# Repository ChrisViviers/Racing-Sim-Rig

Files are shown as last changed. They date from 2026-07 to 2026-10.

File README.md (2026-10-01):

# DIY Sim Racing Wheel & Gear-Driven Pedals (Raspberry Pi Pico 2 + Adafruit AS5600)

A high-precision, zero-friction USB Sim Racing Steering Wheel and Pedal set built using a **Raspberry Pi Pico 2WH** (RP2350 microcontroller), an **Adafruit AS5600** magnetic rotary encoder over I2C, gear-driven potentiometer pedals, custom tactile buttons, and a laser-cut/3D-printed rig frame.

This project reads 12-bit contactless magnetic steering data (0–4095) and 16-bit analog potentiometer pedal data, mapping them down to clean, unsigned 8-bit HID Gamepad axes (0–255) in CircuitPython.

## Table of Contents

- [Features](#features)
- [Hardware Bill of Materials](#hardware-bill-of-materials-bom)
- [3D Printed & Laser Cut Parts](#3d-printed--laser-cut-parts)
- [Pinout and Wiring](#pinout-and-wiring)
- [Software Setup](#software-setup)
- [Pedal Calibration](#pedal-calibration)

---

## Features

- **Contactless Precision Steering:** Uses the Adafruit AS5600 magnetic sensor to track a diametrically magnetized magnet with zero physical wear.
- **Gear-Driven Pedal:** Stepped-up gear ratio assembly (80T pedal gear to 20T pot gear, connected by a timing belt) provides smooth, high-resolution pedal modulation.
- **RP2350 Microcontroller:** Powered by the Raspberry Pi Pico 2WH running CircuitPython.
- **8 Integrated Inputs:** Support for 8 tactile push buttons or paddle shifters using internal pull-up resistors.
- **Auto-Inverting Pedal Calibration:** Robust calibration math handles custom potentiometer mechanical sweep directions (whether voltage sweeps up or down) automatically.
- **Modular RJ45 Cabling:** Floor pedal signals route up to the steering base through a standard Cat5e Ethernet patch cable and RJ45 breakout modules.
- **Plug-and-Play USB HID:** Enumerates directly as a standard USB Gamepad recognized by games like RaceRoom, Assetto Corsa, and iRacing without third-party software.

---

## Hardware Bill of Materials (BOM)

| Component | Quantity | Description / Notes |
| --- | --- | --- |
| **Raspberry Pi Pico 2WH** | 1 | RP2350 microcontroller running CircuitPython |
| **Adafruit AS5600 Breakout** | 3 | 12-bit I2C Magnetic Rotary Encoder |
| **Diametric Magnet** | 3 | Neodymium disc magnet (**must be diametrically magnetized**) |
| **10k Linear Potentiometers (B10K)** | 2 | Throttle and brake pedal sensors |
| **Switches** | 2 | Inputs for wheel buttons and paddle shifters |
| **Timing Belt & Pulleys** | Set | Drives the 20T potentiometer gear from the 80T pedal gear |
| **RJ45 Breakout Modules** | 4 | Modular connection for floor pedals to wheel base |
| **Cat5e / Cat6 Patch Cable** | 2 | Umbilical cable connecting pedals to steering wheel housing |
| **8mm Steel Rod & Bearings** | Set | Shaft stock used across the pedal, steering, and shifter parts  |
| **Laser Cut / 3D Printed Parts** | Set | See [3D Printed & Laser Cut Parts](#3d-printed--laser-cut-parts) |
| **Prototyping Board** | 1 | Circuit interconnects |
| **M5x35 Nuts & Bolts** | 20 | Connecting Laser Cuts |
| **M5x16 Nuts & Bolts** | 15 | Connecting Laser Cuts |
| **M5 Threaded Inserts** | 4 | Connecting Laser Cuts |
| **M3x16 Nuts & Bolts** | 20 | Connecting Laser Cuts |
| **M2.5x20 Nuts & Bolts** | 4 | Connecting Laser Cuts |
| **M2.5x16 Nuts & Bolts** | 12 | Connecting Laser Cuts |
| **6mm MDF Sheert 1000mmx600mm** | 1 | Material for Laser Cuts |
| **85mm Compression Spring** | 2 | For Lifting Pedals |
| **Qwiic JST-SH 4-pin to Male Jumper Wires** | 3 | For Connecting AS5600 sensors |
| **8mm Shaft Collar** | 4 | For Keeping Rods in Place |
| **200mm Male to Male Jumper Cables** | 4 | Circuit interconnects |
| **100mm Male to Male Jumper Cables** | 12 | Circuit interconnects |
| **8mm Pillow Block Bearing** | 6 | Connecting Laser Cuts |
| **8mm 8mm Flange Pillow Block Bearing** | 4 | Connecting Laser Cuts |
| **8mm Steel Rod & Bearings 90mm** | 1 | Shaft stock used across the pedal, steering, and shifter parts  |
| **8mm Steel Rod & Bearings 200mm** | 1 | Shaft stock used across the pedal, steering, and shifter parts  |
| **8mm Steel Rod & Bearings 160mm** | 2 | Shaft stock used across the pedal, steering, and shifter parts  |
| **8mm Steel Rod & Bearings 70mm** | 2 | Shaft stock used across the pedal, steering, and shifter parts  |
| **8mm Steel Rod & Bearings 125mm** | 2 | Shaft stock used across the pedal, steering, and shifter parts  |

---

## 3D Printed & Laser Cut Parts

All CAD source files are in the repository root:

| File | Description |
| ---- | --- |
| [`racingSimPotFullLaser6mm.svg`](https://github.com/ChrisViviers/Racing-Sim-Rig/blob/main/racingSimPotFullLaser6mm.svg) | Laser cut template for the entire rig frame (6mm material). |
| [`RacingSim HE Blueprint.svg`](https://github.com/ChrisViviers/Racing-Sim-Rig/blob/main/RacingSim%20HE%20Blueprint.svg) | Laser cut template for the entire rig frame AS5600 Alternative (6mm material). |
| [`Racing Wheel.stl`](https://github.com/ChrisViviers/Racing-Sim-Rig/blob/main/Racing%20Wheel.stl) | 3D printable racing wheel. |
| [`8mmRodTAdapterPedal.stl`](https://github.com/ChrisViviers/Racing-Sim-Rig/blob/main/8mmRodTAdapterPedal.stl) | T-adapter for the pedal that attaches a rod perpendicular to another rod in the pedal assembly. |
| [`80TGearPedalAdapter.stl`](https://github.com/ChrisViviers/Racing-Sim-Rig/blob/main/80TGearPedalAdapter.stl) | 80-tooth gear that attaches to the pedal. |
| [`20TGear10kPotAdapter.stl`](https://github.com/ChrisViviers/Racing-Sim-Rig/blob/main/20TGear10kPotAdapter.stl) | 20-tooth gear that attaches to the potentiometers; connected to the 80T pedal gear via a timing belt. |
| [`8mmRodMagnetAdapter.stl`](https://github.com/ChrisViviers/Racing-Sim-Rig/blob/main/8mmRodMagnetAdapter.stl) | Attaches the steering wheel's AS5600 magnet to an 8mm shaft. |
| [`ShifterLaserToShaftAdapter.stl`](https://github.com/ChrisViviers/Racing-Sim-Rig/blob/main/ShifterLaserToShaftAdapter.stl) | Adapts the laser-cut design to an 8mm shaft for the sequential shifter. |

---

## Pinout and Wiring

### 1. Steering & Pedal Connections

| Sensor / Component | Module Pin | Pico 2 Pin | Function |
| --- | --- | --- | --- |
| **AS5600 Steering** | VIN | 3.3V (Pin 36) | Power Rail |
| **AS5600 Steering** | GND | GND (Pin 38)  | Ground Rail |
| **AS5600 Steering** | SDA | GP0 (Pin 1) | I2C Data |
| **AS5600 Steering** | SCL | GP1 (Pin 2) | I2C Clock |
| **Throttle Potentiometer**  | Pin 1 (Outer)  | 3.3V (Pin 36) | Power Rail |
| **Throttle Potentiometer**  | Pin 2 (Center) | GP26 (Pin 31) | ADC0 Analog Input |
| **Throttle Potentiometer**  | Pin 3 (Outer)  | GND (Pin 38)  | Ground Rail |
| **Brake Potentiometer** | Pin 1 (Outer)  | 3.3V (Pin 36) | Power Rail |
| **Brake Potentiometer** | Pin 2 (Center) | GP27 (Pin 32) | ADC1 Analog Input |
| **Brake Potentiometer** | Pin 3 (Outer)  | GND (Pin 38)  | Ground Rail |

### 2. Modular Pedal Extension (RJ45 / Cat5e)

| RJ45 Pin  | Pico 2 / Wheel Base | Floor Pedal Box | Function |
| --- | --- | --- | --- |
| **Pin 1** | 3.3V (Pin 36) | Potentiometer Pin 1 | Power Rail |
| **Pin 2** | GND (Pin 38) | Potentiometer Pin 3 | Ground Rail |
| **Pin 3** | GP26 (ADC0) | Potentiometer Pin 2 | Throttle Signal Line |
| **Pin 4** | GP27 (ADC1) | Potentiometer Pin 2 | Brake Signal Line |

### 3. Button Wiring (Active-LOW)

All buttons connect between their designated GPIO pin and GND (using the Pico's internal pull-up resistors):

- **Button 1:** GP6 -> Switch -> GND
- **Button 2:** GP7 -> Switch -> GND
- **Button 3:** GP8 -> Switch -> GND
- **Button 4:** GP9 -> Switch -> GND
- **Button 5 (Left Shifter):** GP10 -> Switch -> GND
- **Button 6 (Right Shifter):** GP11 -> Switch -> GND
- **Button 7:** GP12 -> Switch -> GND
- **Button 8:** GP13 -> Switch -> GND

---

## Software Setup

### Prerequisites

1. Download the latest CircuitPython `.uf2` firmware for the **Raspberry Pi Pico 2**.
2. Download the official **Adafruit CircuitPython Library Bundle**.

### Installation

1. **Flash CircuitPython:** Hold down the `BOOTSEL` button on your Pico 2, connect it to your PC via USB, and drop the downloaded `.uf2` file onto the `RPI-RP2` drive.
2. **Install Libraries:** Copy `adafruit_as5600.mpy` from the Adafruit bundle into the `lib/` directory on your `CIRCUITPY` drive.
3. **Add Project Files:** Copy `boot.py`, `code.py`, and `hid_gamepad.py` from this repository directly to the root of your `CIRCUITPY` drive.
4. **Reboot:** Eject the drive safely and reconnect the Pico 2 to initialize the new USB device profile.

---

## Pedal Calibration

Because custom gear-driven potentiometers vary by build, calibrate your pedal limits in `code.py`:

1. Run a basic analog read script to measure the raw ADC value at **Rest** and **Floored** for each pedal.
2. Update the constants in `code.py`:

\`\`\`python
#### Measured calibration limits
THROTTLE_REST    = 800
THROTTLE_FLOORED = 23300
BRAKE_REST       = 3400
BRAKE_FLOORED    = 24000
\`\`\`

The mapping function handles both increasing and inverted potentiometer sweep directions automatically, so it doesn't matter which end of the pedal's travel reads the higher raw value.

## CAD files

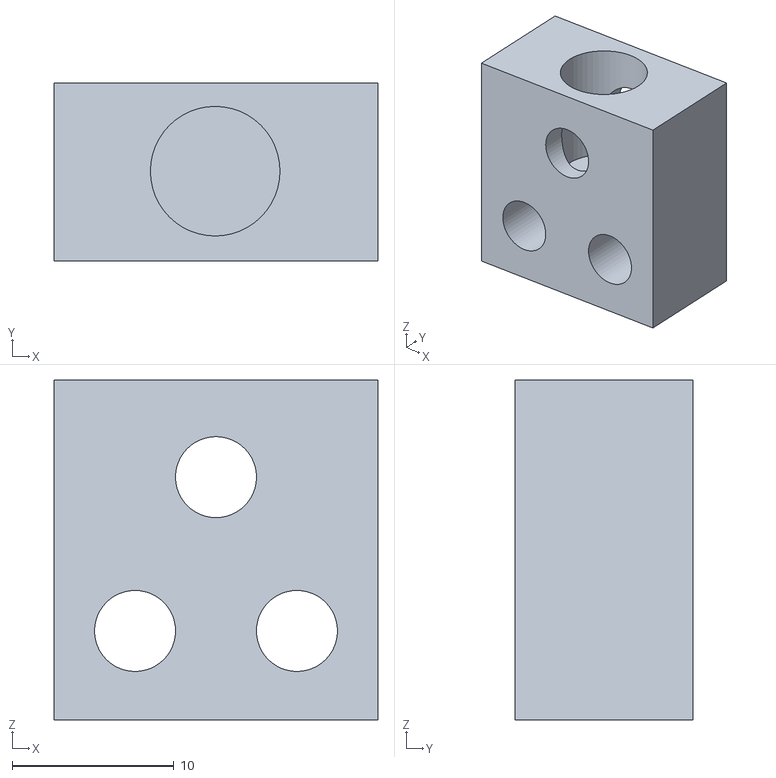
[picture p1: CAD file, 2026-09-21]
ShifterLaserToShaftAdapter.stl
20.0 x 11.0 x 21.0

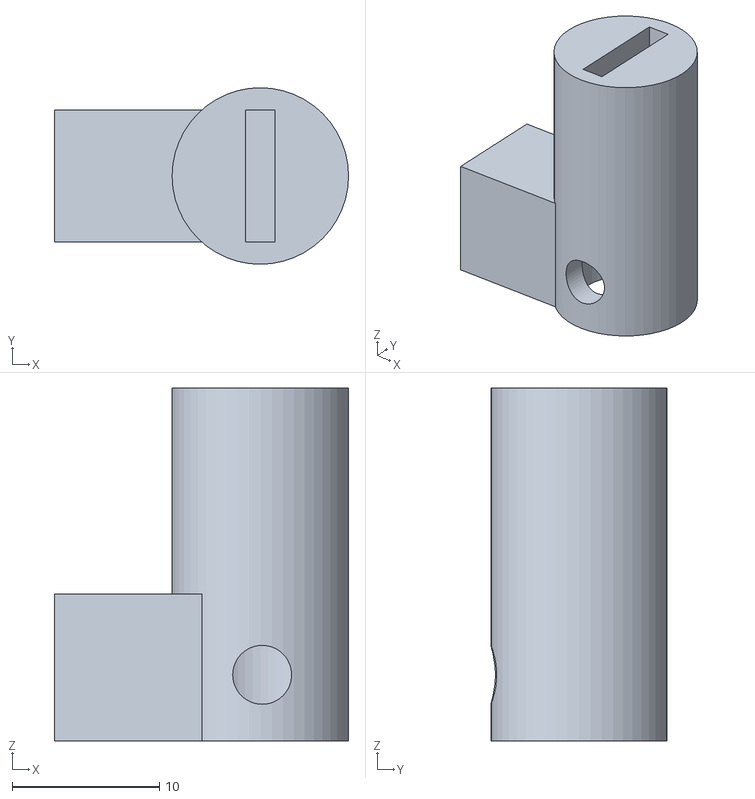
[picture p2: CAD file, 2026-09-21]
8mmRodMagnetAdapter.stl
20.0 x 12.0 x 24.0

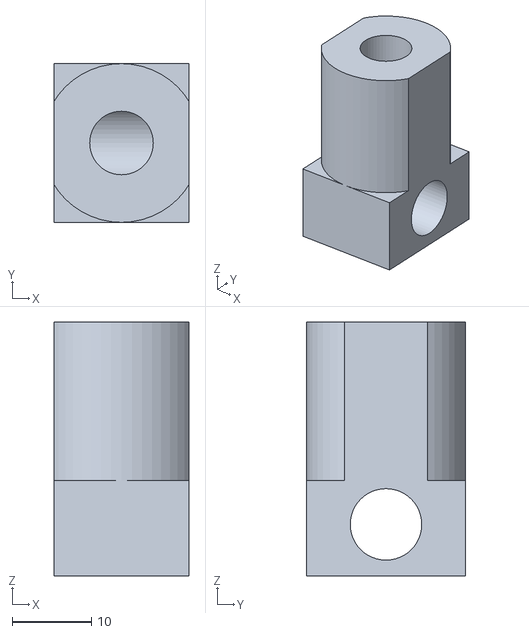
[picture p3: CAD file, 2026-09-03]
8mmRodTAdapterPedal.stl
17.0 x 20.0 x 32.0

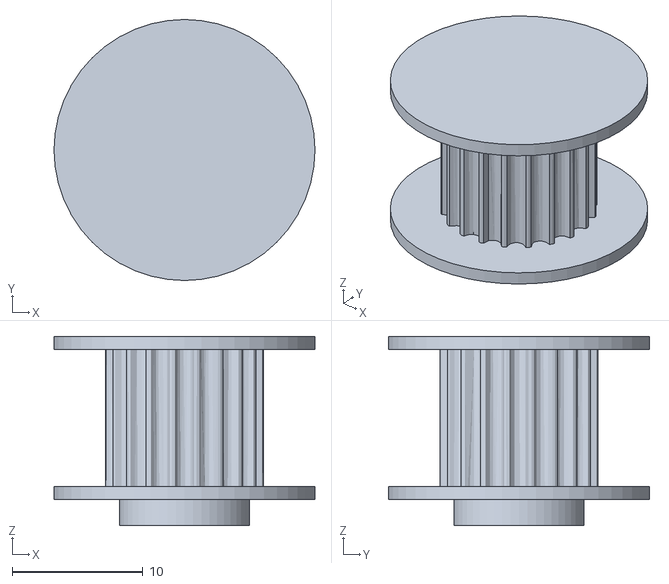
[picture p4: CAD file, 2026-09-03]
20TGear10kPotAdapter.stl
20.0 x 20.0 x 14.5

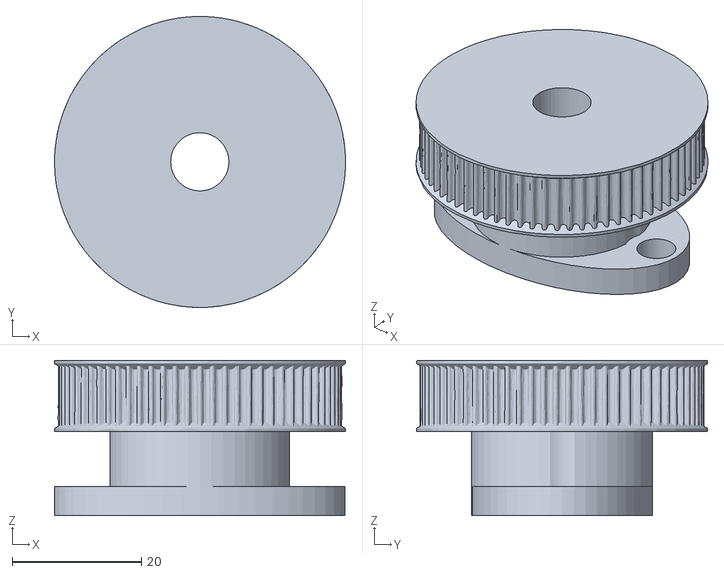
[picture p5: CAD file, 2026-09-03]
80TGearPedalAdapter.stl
45.1 x 45.1 x 24.0

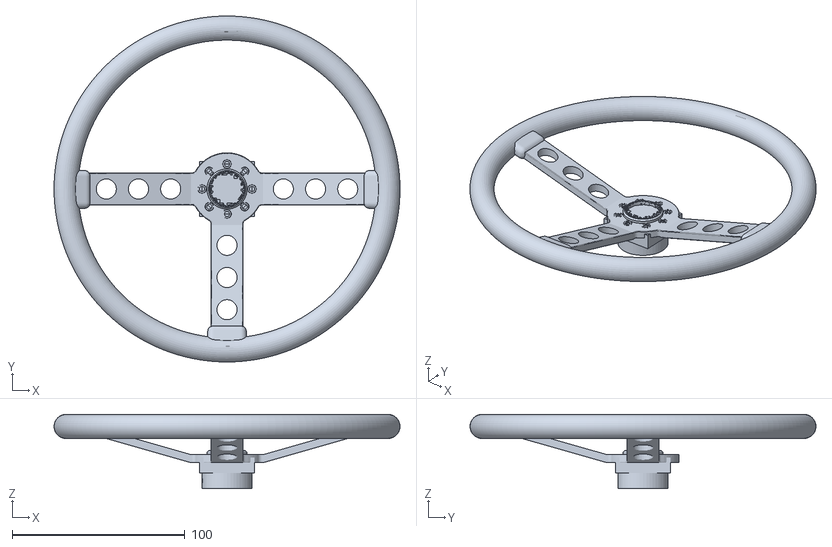
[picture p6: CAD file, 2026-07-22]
Racing Wheel.stl
200.0 x 200.0 x 42.9

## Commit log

2026-09-21 Rename 8mm Rod T Adapter Final.stl to 8mmRodTAdapterPedal.stl
    [8mmRodTAdapterPedal.stl]
2026-09-21 Rename 80T Gear Pedal Adapter.stl to 80TGearPedalAdapter.stl
    [80TGearPedalAdapter.stl]
2026-09-21 Rename Small Gear 10k pot .stl to 20TGear10kPotAdapter.stl
    [20TGear10kPotAdapter.stl]
